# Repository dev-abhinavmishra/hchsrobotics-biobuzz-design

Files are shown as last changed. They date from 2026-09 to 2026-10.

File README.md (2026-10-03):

# BIOBUZZ-Robot

FTC BIOBUZZ-season robot CAD. Fully parametric FreeCAD model — Python
builders regenerate every `cad/*.FCStd` document from a shared
`Parameters` spreadsheet, and three selfcheck gate suites are the repo's
regression contract (all green on main). ~1,090 exportable solids across
six subsystem docs plus the integrated `master_robot.FCStd`, with full
fastener detail.

## For the CAD team (SolidWorks)

**You don't need FreeCAD.** Everything manufacturable is pre-exported to
STEP — the FCStd files are the editable sources only if you want to
change the design itself.

### What to open

| You want | Use |
|---|---|
| The whole robot, assembled | `exports/step/master_robot.step` (one AP203 STEP, ~1,090 parts, each at its true position) |
| One subsystem at a time | `exports/step/subassembly/{drivebase,intake,hopper,electronics,turret,lift}.step` |
| A group of related parts | `exports/step/subassembly/GRP_*.step` (frame, pods, turret rotation, fasteners…) |
| A single part | `exports/step/parts/<NAME>.step` — product names preserved (no anonymous Part__Feature) |
| 2D drawings | `exports/drawings/` — one A4 sheet per unique part as PDF + SVG (TOP/FRONT/RIGHT views, overall dimensions, title block with material + qty), and `exports/drawings/dxf/` R12 flat profiles for the 165 plate parts (ready for waterjet/laser) |
| Bill of materials | `exports/bom/bom.csv` — subsystem, description, material, spec, qty |
| Renders | `exports/renders/*.png` — shaded orthographic previews per subsystem |

### SolidWorks import notes

1. `File → Open → master_robot.step`, import as **assembly** (not
   multibody part). ~1,090 parts — give it a minute. For quicker work,
   import a subsystem STEP instead and mate them yourself (they're in
   world coordinates — parts land exactly where they sit in the master).
2. Units are mm. Part names carry a status suffix (`_VERIFIED`,
   `_VENDOR-PENDING`, `_UNVERIFIED`) — see the checklist below.
3. Non-physical construction geometry (`TOOL_`, `VOL_`, `ENV_`, `REF_`,
   `AXIS_` prefixes) is intentionally excluded from STEP — if you see it,
   it came from an FCStd, not an export.

### Before you cut metal: the verification checklist

Every dimension carries a status label in `exports/parameters.csv`
(and `docs/robot-parameters.md`): **3 VERIFIED** (manual-cited),
**24 VENDOR-PENDING** (goBILDA catalog values awaiting datasheet), and
**245 UNVERIFIED** (assumed). Nothing UNVERIFIED has been measured
against physical hardware — the gates verify parametric integrity,
mounting/declared-contact consistency, envelope fit, and rebuild
determinism, **not** real-world fit.

Measure/confirm before manufacturing, roughly in order of risk:

- **Stock + hardware dims**: all sheet/plate thicknesses, extrusion
  sizes, bearing bores — anything your parts physically mate to
- **Vendor parts**: all `VENDOR-PENDING` goBILDA dims vs the actual
  purchased parts (datasheet or calipers)
- **Ball-path clearances**: column bore Ø99 vs your ball's true
  diameter; chute width 97 mm; port window height
- **Mesh/engagement**: 72T ring + 14T pinion at 72.8 mm center distance;
  belt/chain center distances; lazy-susan race stack heights
- **Mounts**: every fastener lands in a real declared bore (the gates
  prove this geometrically) — but hole sizes/threads are UNVERIFIED
- **Envelopes**: stowed 453.7×454.5×379.0 mm inside the 457.2 cube;
  deployed lift tops 586.5 mm (inside the 609.6 reach / 736.5 height)

### Known design-contact notes (intentional touches/brushes)

- `PORT_FLANGE` sill: the ball rides over the port sill edge on the way
  out (designed ride surface, ~0.5 mm brush).
- `SCRW_CHL_1_0` (leg-2 lip tip) and `ROPE_DYNEEMA` (lift line): the
  ball brushes these ~2–5 mm on the cradle drop — acceptable grazing
  contact for hand-loaded parts; move the rope guide ~8 mm west if it
  ever deflects a ball in testing.
- `CHUTE_PTS + n·46.5` is the *ride* model only — the ball enters leg 1
  on a ballistic transition, rides the bed, and free-falls ~40 mm into
  the cradle mouth (see `dt_lift.py` comments).

### Change the design?

See "Quickstart" below — edit `scripts/freecad/robot_params.py` or the
`dt_*.py` builders, rebuild the affected doc, re-run the gates, then
re-export (`export_step.py`) and re-draw (`make_drawings.py`). The CI
workflow runs all of it on every push to `main`.

---

## Interactive 3D design review

`viewer/` is a self-contained Three.js design-review app for the full
competition robot concept — no CAD software needed:

```bat
cd viewer
python serve.py        :: no-cache dev server (avoids stale JS modules)
:: open http://127.0.0.1:8017
:: `python -m http.server 8017` also works, but hard-refresh if modules look stale
```

Features: 7 subsystems / ~270 placed parts merged into 136 BOM lines, per-part
inspector (spec, qty, notes, bounding size, connected-parts graph), an
**Isolate** button that ghosts everything but the selected part — combined with
Prev/Next it steps through every piece in solo view — exploded view slider,
X-ray and subsystem isolation, animated
mechanisms (mecanum rollers, flywheels, 360° turret, hood, agitator, 2-stage
deposit lift with live rope rigging), a launch demo that slews the turret,
lobs a POLLEN into the HIVE cell and tips it, a lift demo that raises the
cradle ~14.6" and tips the ball, an 18" sizing-cube overlay, and a full
BIOBUZZ field at scale (hives, 4 flowers, loading zones, staged elements).

**Part Explorer** (`Parts` tab in the left panel): every BOM line is listed
per subsystem with a live filter; clicking a part highlights all placed
instances and frames them. The inspector shows spec, quantity, bounding size,
notes, and a **Connected parts** graph — clickable chips jump between mated
parts (motor → pinion → axle → bearings → wheel; winch → spool → rope →
pulleys → stages; hubs → every wire run). Prev/Next steps through the whole
BOM, and **◎ Isolate** solos any part — the solo view follows selection so
stepping parts keeps everything else ghosted.

Production-realism pass: procedural canvas textures (alliance number plates,
AprilTags, foam-tile waffle, motor/hub labels), full wiring loom (motor power,
servo PWM, encoder/sensor JST, battery→switch→hub, slip-ring to the turret),
instanced fastener fields, sealed bearings, #25 chain with pins and a master
link, rail end caps, nylocks, shaft collars, compact-motor clamps, JST wire
connectors, hub LEDs, main-switch detail, zip ties, and a contact shadow.

Performance: repeated geometry (mecanum/omni rollers, star discs, wheel ribs,
slots, spokes, ports, fasteners) renders through InstancedMesh — roughly 200
meshes collapsed into instanced draws; clear polycarbonate uses cheap
alpha-blend instead of a transmission pass (which would double the scene
render), and the shadow map re-bakes only while geometry actually moves.

**Match Demo** (`⏵ Match Demo` button): a ~45-second scripted match —
autonomous pollen intake run (intake rollers spin, balls sweep along the
floor and arc up the throat), turret aims at the CELL AprilTag, feed wheel
meters balls **visibly rising through the clear column** into 3 POLLEN lobs,
teleop mecanum strafe to the alliance NECTAR stash, 2 NECTAR launches that
tip the HIVE, a corner run where the diverter kicks a ball down the load
chute into the cradle, then the lift rises and pours it into the FLOWER
mouth, and a loading-zone park. Cinematic chase/fixed cameras with phase
captions — **drag anytime to take a free spectator camera**, then "Resume
cinematic camera" to hand control back. Subsystem motion is gated per phase
(intake spins only while collecting, flywheels only while shooting). Every
scored ball stays in the cell. Click the button again to abort.

Design intent: 17.5×17.5×14.9" — starts legal inside the 18" cube (R101); the
deposit lift is the only expansion and tops out ~26", inside the R105 29"
vertical cap with hard-stop collars (G416). Over/under intake → inclined
hopper → feed column through the turret axis → dual-flywheel turret launcher
with AprilTag camera lobs POLLEN/NECTAR into the HIVE cell. For FLOWERS the
same column doubles as the elevator — a servo Y-flap diverts a ball through a
side port into the lift cradle, which deposits NECTAR into the ~4" mouth at
~22" (a lob into a 4" opening for a 3.6" ball was rejected as unreliable).

---

## Layout

```
cad\                  master_robot.FCStd (styled view baked in) +
                      master_robot_view.FCStd (styled copy)
cad\drivebase\        drivebase.FCStd     cad\intake\    intake.FCStd
cad\electronics\      electronics.FCStd   cad\hopper\    hopper.FCStd
cad\turret\           turret.FCStd        cad\lift\      lift.FCStd
cad\archive\          timestamped backups (auto-created before overwrites)
scripts\freecad\      build_*.py builders, selfcheck_overhaul*.py gates,
                      partkit/dt_* helpers, export/drawing/render tools
scripts\freecad\legacy\  superseded pre-overhaul concept scripts
scripts\validation\   ci_selfcheck.sh + probes
docs\                 project documentation (see index below)
exports\              STEP parts/subassemblies, bom.csv, mount_graph.json,
                      meta/, renders/, drawings/ (see exports/README.md)
viewer\               self-contained Three.js design-review app
.devin\               agent instructions and generator state
.github\workflows\    cad-verify.yml — rebuild + gates on every push to main
```

## Quickstart

Requires FreeCAD **1.1.3** (`freecadcmd` on PATH — AppImage extract or apt;
gate signatures are version-sensitive, other 1.1.x builds may differ):

```bash
freecadcmd scripts/freecad/build_drivebase.py
freecadcmd scripts/freecad/build_electronics.py
freecadcmd scripts/freecad/build_intake.py
freecadcmd scripts/freecad/build_hopper.py
freecadcmd scripts/freecad/build_turret.py
freecadcmd scripts/freecad/build_lift.py
freecadcmd scripts/freecad/build_master_robot.py   # integrated assembly
```

Exports + previews (regenerate after rebuilding):

```bash
freecadcmd scripts/freecad/export_step.py      # STEP parts/subassemblies + bom/meta
freecadcmd scripts/freecad/render_png.py       # exports/renders/*.png
freecadcmd scripts/freecad/make_view_copy.py   # restyle master_robot_view.FCStd
freecadcmd scripts/freecad/make_drawings.py    # exports/drawings/: A4 PDF+SVG
                                               # sheets + plate DXFs + manifest
```

Regression gates (must stay green — these are the repo's contract):

```bash
bash scripts/validation/ci_selfcheck.sh   # all selfcheck_overhaul* gates,
                                          # or run each directly:
freecadcmd scripts/freecad/selfcheck_overhaul01.py   # 45 gates
freecadcmd scripts/freecad/selfcheck_overhaul02.py   # 61 gates
freecadcmd scripts/freecad/selfcheck_overhaul03.py   # 73 gates
```

The `.github/workflows/cad-verify.yml` workflow runs the same build +
gates on every push to `main` (cached FreeCAD 1.1.3 install) and uploads
selfcheck output + `exports/` as artifacts.

Viewing in the FreeCAD GUI: just open `cad\master_robot.FCStd` (or the
identical `cad\master_robot_view.FCStd`). The file carries baked-in view
state: non-physical `ENV_*`/`VOL_*`/`REF_*` volumes and field markers are
hidden, subsystem solids are colored, and the camera opens on a fitted
isometric. Re-run `make_view_copy.py` after any rebuild to restore that
styling; `view_robot.py` does the same for a live session (Macro ->
Macros -> Run).

All scripts are idempotent and resolve paths relative to their own location.
See `docs/setup.md` for details and `docs/coordinate-system.md` for the axis
convention used by every model.

## Documentation index

- `docs/setup.md` — FreeCAD install path + exact build commands
- `docs/robot-parameters.md` — every named parameter: value, unit, status, source
- `docs/coordinate-system.md` — origin and axis convention
- `docs/cad-architecture.md` — how the FCStd files are structured and rebuilt
- `docs/mechanism-architecture.md` — placeholder plan for all six subsystems
- `docs/requirements.md` — manual-cited constraints vs assumptions
- `docs/design-decisions.md` — why things are built the way they are
- `docs/open-questions.md` — unresolved questions
- `docs/change-log.md` — build history
- `docs/eval-sprint03-independent.md` — independent adversarial eval of the
  gates + probes (ball-path findings, since fixed)
- `docs/initial-autonomous-build-report.md` — what the autonomous build produced

## Honesty notice

`VERIFIED` values are cited to a Competition Manual rule/section;
goBILDA-catalog values are `VENDOR-PENDING` pending datasheet/purchase;
everything else is an assumption labeled `UNVERIFIED`. The selfcheck gates
verify parametric integrity, mounting/declared-contact consistency,
envelope fit, and rebuild determinism — the UNVERIFIED checklist above is
what still needs a human + physical hardware.

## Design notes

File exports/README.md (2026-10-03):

# Exports — sprint-04 (as-built)

Generated by `scripts/freecad/export_step.py`,
`scripts/freecad/make_drawings.py`, `scripts/freecad/render_png.py`, and
the `selfcheck_overhaul0{1,2,3}.py` gate transcripts (rerun after any
rebuild). All artifacts derive from the parametric FreeCAD model —
FreeCAD is the source of truth; these files are read-only derivatives.

## Layout

| Path | Contents |
|---|---|
| `step/parts/<NAME>.step` | One AP203 STEP per exportable solid (1089 files). PRODUCT records carry the FreeCAD object names — reimported parts come back named, not anonymous Part__Feature blobs. Each is positioned by its object's global placement — import matches the FCStd exactly. |
| `step/subassembly/*.step` | Assembly-group STEP files (GRP_DRIVEBASE, GRP_FRAME, GRP_PODS, GRP_ELECTRONICS, GRP_INTAKE, GRP_HOPPER, GRP_TURRET, GRP_TURRET_ROT, GRP_LIFT, GRP_FASTENERS) plus subsystem slices (`drivebase.step`, `electronics.step`, `intake.step`, `hopper.step`, `turret.step`, `lift.step`). |
| `step/master_robot.step` | The complete master assembly in one STEP. Reimported and solid-counted as part of the export gate. |
| `drawings/` | Engineering-drawing output from `make_drawings.py`: one A4-landscape sheet per unique part (580 sheets) as PDF + SVG with TOP/FRONT/RIGHT views, overall-dimension callouts and a title block, plus flat R12 DXF profiles in `drawings/dxf/` for the 165 plate-like parts. See `drawings/README.md`. |
| `bom/bom.csv` | Bill of materials aggregated across subsystem BOM rows — subsystem, description, material, spec, status, qty, object list. |
| `parameters.csv` | Every `Parameters` spreadsheet alias: value, unit, status, source note. Mirrors `docs/robot-parameters.md`. |
| `mount_graph.json` | The declared pair tables: joints (members + bolts + nuts), faces, embeds, journals, contacts, ground census, BOM rows — what GEO/FAST gates verify. |
| `meta/<tag>.json` | Same pair tables per document (drivebase / electronics / intake / hopper / turret / lift / master). |
| `renders/*.png` | Shaded orthographic previews (`render_png.py`): front/side/top/iso per document, subsystem palette. |
| `selfcheck_overhaul0{1,2,3}.txt` | Latest gate transcripts (45, 61 and 73 gates respectively — all PASS). |

## Status labels

Every exportable solid name/label carries a status suffix:
`_VERIFIED` (manual-cited), `_VENDOR-PENDING` (goBILDA-catalog, awaiting
datasheet), `_UNVERIFIED` (assumed). Construction intermediates are
`TOOL_`-prefixed with unique status-bearing labels so no solid exports
an unlabeled or duplicated label (PROV1/PROV2 gates).

## Notes

- The ball route: intake mouth → inclined hopper floor → feed wheel →
  clear column bore → metering gate → turret launcher (POLLEN into the
  HIVE cell), or — with the Y-flap diverter — out the `COL_PORT`
  window → `PORT_FLANGE` → two-leg LOAD_CHUTE → lift cradle → FLOWER
  mouth (NECTAR).
- The yaw drive is an external ring mesh: 72T ring on the turret's
  outer rim driven by a 14T pinion at 72.8 mm centre distance, yaw
  servo mounted at −Y of the turret axis under the deck.
- The lazy-susan Z-stack is resolved bottom-up: deck 244–248 mm,
  susan races 248–256.5 mm, ring gear 256.5–263 mm, plate 263–267 mm.
- The load chute is two legs (28.5° and 21.8°) from the column port to
  the cradle's Ø99 mm park bore at z ≈ 140 mm.
- The electronics expansion hub sits on the right frame rail outer
  face (|y| ≈ 200 mm).
- Values marked UNVERIFIED/VENDOR-PENDING are placeholders pending
  measurement or datasheet confirmation — see
  `docs/robot-parameters.md` before manufacturing.
- The frame footprint is 444.5 mm square; enumerated fastener classes
  protrude up to ~3 mm into the start-cube margin.
- Older deliverables live under `../cad/archive/` (pre-overhaul FCStds)
  and `../scripts/freecad/legacy/` (concept scripts).

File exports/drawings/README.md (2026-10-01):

# exports/drawings/

Engineering-drawing output, generated by
`freecadcmd scripts/freecad/make_drawings.py` (see that file's docstring
for the environment-variable selectors).

- `<doc>_<part>.svg` / `<doc>_<part>.pdf` — one A4-landscape sheet per
  unique part (identical instances are grouped and shown as QTY): TOP,
  FRONT and RIGHT-SIDE views, overall extent-dimension callouts on each
  view, and a title block (part, material, spec, qty, rev, scale).
- `dxf/<doc>_<part>.dxf` — flat R12 profile for every plate-like part
  (thin+wide geometry, or a plate-hint name such as deck/base/cheek/
  bracket/pan/gusset), face-normal rotated to +Z, origin at the
  bounding-box minimum. Ready for laser/waterjet nesting.
- `manifest.json` — machine-readable per-part report (doc, qty, bbox,
  material, plate flag, output paths).
- `manifest.txt` — the same per-part list as printed on stdout.
- `sample/` — a few representative sheets + DXFs kept in-repo for
  review. The full per-run output (~1,150 sheet files + ~190 DXFs,
  ~140 MB) is gitignored; regenerate it any time with the command
  above.

Regenerate after any geometry change; the part list is enumerated from
the documents, not hardcoded.

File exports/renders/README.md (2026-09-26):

# exports/renders — BIOBUZZ-Robot

Rendered previews of the placeholder master assembly:

- `master_{front,side,top,iso}.svg` — shaded vector renders
  (`render_views.py`): painted facets, per-subsystem colors,
  silhouette/sharp-edge overlay, legend.
- `master_{front,side,top,iso}.png` — shaded raster renders
  (`render_png.py`): z-buffered so interpenetrating solids occlude
  correctly; same palette and views as the SVGs.
- `fc_screenshot.png` — reference capture of the styled GUI view
  (`cad/master_robot_view.FCStd`, produced by `make_view_copy.py`).
- `render_log.txt`, `view_log.txt` — script run logs.

Every file in this folder is prototype material:
**PROTOTYPE / VERIFY BEFORE MANUFACTURING**

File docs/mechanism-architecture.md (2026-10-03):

# Mechanism architecture — BIOBUZZ sprint-01 foundation

Sprint 01 rebuilt the foundation (frame + drivetrain + odometry pods +
electronics tray) in `cad/master_robot.FCStd`, with
`cad/drivebase/drivebase.FCStd` and `cad/electronics/electronics.FCStd`
as subsystem slices. All three documents are generated by thin wrappers
over the shared builder `scripts/freecad/dt_build.py`, so subsystem
geometry is byte-for-byte identical to the corresponding master regions
(DET3 gate verifies name + bbox + volume parity).

Every number below is cited (VERIFIED), goBILDA-catalog-representative
(VENDOR-PENDING), or assumed (UNVERIFIED) on the same line; canonical
values live in `docs/robot-parameters.md` and the `Parameters`
spreadsheet inside each FCStd. Frame convention:
`docs/coordinate-system.md` (+X forward, +Y left, +Z up, origin on the
tile at the footprint center).

## Frame — goBILDA 1120-series U-channel ring

- `FRAME_RAIL_L/R`: two 444.5 mm U-channels (`rail_size` 48 mm
  VENDOR-PENDING, `rail_wall` 2.5 mm UNVERIFIED), lateral offset
  `rail_lat_off` = `wheel_lat_off − wheel_out_gap` so the rail inner
  face clears the wheel envelope. Real wall-grid hole rows cut through
  flange and web faces; axle-clearance bores let the drive shafts pass.
- `FRAME_CROSS_B/F`: front/rear crossmembers at `cross_x_off`, ends
  bolted into the side-rail inner faces (`tie_web` joints).
- `GUSSET_UR/UL/BR/BL` inside-corner brackets + `GUSSETU_/GUSSETX_`
  twin plate rows, 4 fasteners per gusset (rail + crossmember split).
- `CROWN_POST_L/R` stand the crown structure off the rail tops;
  `ENDCAP_*` close the six open channel ends.
- `BELLY_PAN` 2 mm sheet (`pan_z` 26.67) hung under the frame by six
  `PAN_BRKT_*` L-brackets (2 leg bolts + 1 foot bolt each) plus four
  front/rear pan bolts — the pan carries the battery, switch bracket,
  and the odometry spring pads.
- `PLATE_NUM_*` number plates (front + side), `TIE_RB_*` rear-brace
  ties.
- `DECK_*`: 3 mm deck panels at `deck_z` 85.3 held by eight
  `DECK_POST_*` standoffs off the rail webs (post_foot + deckpost_web +
  deckpost_panel joints).

## Drivetrain — 4× 96 mm mecanum (corner-parameterized)

Each corner (`build_corner`, tags FL/FR/RL/RR) is generated by the same
code path with only sign flips — there is no per-corner copy-paste:

- `WHEEL_ASSY_*` `App::Part` carrier at `wheel_lon_off`/`wheel_lat_off`/
  `wheel_dia/2`; children hold local-frame geometry:
  - `WHEEL_HUB_*`: Ø26 hub (`hub_dia`) with a real hex REX bore
    (`rex_af` 8 mm VENDOR-PENDING) and a radial `BOLT_HUB_*` M4 pinch
    setscrew into the shaft flat.
  - `WHEEL_PLATE_*_IN/OUT`: Ø92 side plates (`wplate_dia`), chamfered,
    sharing the hub's hex bore; rollers trapped between them.
  - `ROLLER_*_00..09_B`: ten Ø14×24 rollers (`mec_roll_*`) on 45° slant
    axes — the tire-contact census registers all ten per wheel.
- `AXLE_*`: hex live axle through the hub's hex bore, M8-threaded tip
  (`shaft_tip_d`/`shaft_tip_len`) carrying `WSH_`/`NUT_AXLE_`/
  `COLLAR_` retention and a `PINION_` drive dog.
- `BRG_IN_*`/`BRG_OUT_*`: flange bearing blocks (`bear_*` dims) flush
  on the rail cavity faces, **real Ø9.6 REX clearance bores centered on
  the wheel axis** (the bore + pilot sit at the block center — an
  earlier revision bored them at the plate corner, which would have
  trapped the axle in solid metal). 4 flange bolts each → cavity
  rivnuts.
- `MOTOR_*`: 5203-class Ø36 can + Ø40 gearbox (`motor_*`,
  VENDOR-PENDING), hex socket bore for the axle tail, 4 face taps.
  Motor face registers on `MOUNT_PLATE_*` (348.5×48.3×3.05 mm,
  `mplate_*`) which bolts to the rail inner face with 12 countersunk
  `BOLT_MPL_*` + cavity nuts. `CLAMP_*_1/2` split-ring clamps cradle the
  gearbox can (declared curved-face contact, not a journal) with shared
  ear bolts through clamps + plate + wall.
- `PINION_*` on the outboard shaft end + axle `WSH_`/`NUT_AXLE_` lock
  stack.

## Odometry pods — 3 tracking wheels

- `ODO_MOUNT_*` blocks bolted under the belly pan (`odo_mount` joint);
  `ODO_PIVOT_*` pins carry `ODO_ARM_*` swing arms with real journal
  pairs (`odo_pivot`).
- `ODO_WHEEL_*` Ø48 tracking wheels (`odo_wheel_d` VENDOR-PENDING) on
  `ODO_AXLE_*` pinions through arm bores (`odo_wheelpin` journal) —
  exactly three ground contacts besides the four mecanums (ground
  census gate).
- `ODO_SPRING_*`: wire-formed preload struts (polyline + ball) from the
  arm tail to a pan pad — declared spring contacts, geometry baked
  (not param-bound) by contract.
- `ODO_ENC_*` encoder body per pod with `SCRW_ENC_*` self-taps.

## Electronics — belly-tray package

- `ELEC_SHELF` 2 mm tray at `shelf_z` 85.3 on four `STANDOFF_*`
  (shelf_so joints). `HUB_CTRL` mounts to the belly pan; `HUB_EXP`
  is face-mounted on the `FRAME_RAIL_R` out-wall via a fused 3 mm
  back flange + 4 M4 bolts to cavity nuts (the shelf site sits
  inside the S17 seat sphere envelope).
- `BATTERY` 95×65×40 (`batt_*`) on the belly pan, strapped by
  `BATT_STRAP_0/1` (strap_pan joints + pan-side nuts).
- `SWITCH_BRKT` on the pan face (2 pan bolts) with `MAIN_SWITCH` and 2
  `SCRW_SW_*` self-taps.
- Sprint-01 wiring subset: `WIRE_BATT_SW`, `WIRE_SW_CTRL`,
  `WIRE_HUB_RS485`, four `WIRE_MTR_*` motor leads, three `WIRE_ENC_*`
  encoder leads — both endpoints must exist; harness segments are
  baked (`wire_d` Ø3) and declared via contact/embed pairs.

## Fastener model (R7 hybrid)

- Every bolt is a real solid (`pk.bolt`/`_flathead`/`pk.hex_nut`/
  `pk.rivnut`) spanning its joint: **real clearance bores through
  pass-through members**, embed declared only into the terminal
  threaded member (`meta['embeds']`).
- `meta['joints']` records per-joint membership + bolt/nut lists;
  FAST1 enforces per-class minimums (bearing 4/motor-face 4/mount
  plate 12/clamp 2/gusset 2+2/post 4/pan-bracket 2+1/odo 2+1+1/…).

## Declared-pair tables

`dt_build.finish_doc` writes `exports/meta/<tag>.json`:
`joints` (member/bolt/nut sets), `faces` (mount face pairs, GEO3
≤0.1 mm), `journals` (coaxial shaft↔bore pairs, GEO4 ≤0.2 mm),
`embeds` (terminal fastener + press-fit embeds), `contacts`
(spring/wire/incidental touch), `ground` (exactly 4 mecanum + 3
odometry wheels), `bom` (per-subsystem spec rows → `exports/bom/bom.csv`).

## Verification

`selfcheck_overhaul01.py` gates 21 checks: GIT (sources committed),
DET (shared-builder parity), PAR (alias set + bound expressions),
PROV (status labels), DAG (pair references), ASM (group coverage),
FAST (joint hardware), GEO (census, undeclared overlap ≤0.5 mm³,
mount contacts ≤0.1 mm, journal axes ≤0.2 mm, motor axes ≤0.3 mm/1°),
ENV (envelope bounds), XPT (per-part/subassembly/master STEP, tables),
GUI (doc health). Current: **21/21 PASS**.

## Sprint-02/03 scope guard

Intake, hopper, turret/shooter, lift, servos, camera, and USB-loom
solids are intentionally absent from the master — they belong to
later sprints. Do not add them.

# Sprint-02 — game-piece path (intake + hopper/feed)

Sprint 02 builds the under-crown ball route on the same frame, shared
through `dt_path.py` into `cad/intake/intake.FCStd`,
`cad/hopper/hopper.FCStd`, and `cad/master_robot.FCStd` (DET3 parity).
Frame convention unchanged (+X forward, +Y left, +Z up; the hopper
occupies the -X half).

## Intake — over/under dual roller

- `INT_CHEEK_L/R`: cheek plates flush-bolted to the rail inner walls
  (`cheek_lat_off` 130.5), pivot pins + crown-post lock bolts
  (`cheek_pivot`/`cheek_lock` joints) — the whole assembly swings
  between stowed and deployed poses.
- `ROLLER_LOW`: full-width Ø50.8 ribbed traction roller
  (`roller_low_r` 25.4) on a wall-borne hex axle, driven from the
  intake motor through a #25 chain run inside the right rail channel
  (`SPROCKET_9T`→`SPROCKET_16T`, `MASTER_LINK` clip joint).
- `ROLLER_TOP`: Ø78.7 compliant star roller (`roller_top_r` 39.35 on a
  `star_core_r` 22 core) on `FLOAT_SLIDE_*` acetal blocks —
  `float_travel` 17.8 mm of sprung travel absorbs Ø91 NECTAR.
  `SPRING_POST_*` Ø8 posts stand on the cheek towers; the
  `TORSION_SPRING_*` coils wind snug on the exposed post span outboard
  of the cheek face, leg tips seating into the slide + cheek faces
  (declared embeds).
- `BELT_XROLL` crossed quarter-twist belt counter-rotates the star
  roller off the lower axle — the crossing survives the 17.8 mm float
  where a rigid spur pair could not. `TENS_ARM` + `TENS_IDLER` ride on
  the `TENS_POST` pivot; `TENS_SPRING` preloads the arm (coil on the
  post's exposed span, legs into arm + cheek faces).
- `THROAT_GUARD`: crown-top deflector into channel nuts.
- Nip geometry: `nip_rest_gap` ≈ 81.6 ≥ 73.2 for POLLEN at rest, opens
  ≥ 91 for NECTAR at full float.

## Hopper — inclined magazine + clear feed column

- `HOP_FLOOR`: inclined magazine plate (`hopper_incline` 20°) on
  wall-side ledges (`hop_ledge_*` joints), descending toward the feed
  corner. `HOP_APRON` lips under the floor's low edge (declared lap
  embed). `HOP_CURB` rear curb behind the column mouth.
- `HOP_WALL_L/R`: 3 mm walls at `hop_wall_y` ±60 bounding the lane.
  The L wall carries an `R76` notch clearing the +Y port corridor (the
  Ø93 sphere passes the wall, not just the flange bore).
- `AGIT_*`: agitator servo at the low corner (`agit_x/y/z`) + paddle
  + horn; bracket and servo each take 4 screws.
- `FEED_*`: compliant metering feed wheel (`feed_wheel_r` 40.65) on
  `FEED_SHAFT` through a wall bearing (`feed_bearing` joint, 4 bolts),
  1:1 spur drop pair from `FEED_MOTOR` under the incline
  (`SPUR_FEED_M/W` mesh declared as tooth-envelope embed).
  `FEED_SCOOP` guide plate at the column mouth.
- `FEED_COLUMN`: clear Ø110/Ø104 tube on the future turret axis
  (`column_x` −66), z 88→254, seated on `COL_FLANGE` (trimmed to the
  column's +X face) bolted through 4 `COL_POST_*` hex standoffs to the
  belly pan — each post carries a top flange bolt **and** a bottom
  pan bolt (col_post joints, 2 fasteners each).
  - `COL_WIN` +X feed window, ≈93+ clear aperture into the hopper
    lane — the Ø93 ball enters at window level.
  - `COL_GSLOT` slot in the -Y shell + `COL_GBR` horn bore admit the
    gate flag's swing.
  - `COL_PORT` +Y window (the diverter port) over `REF_DIV_PORT`.
- `GATE_*`: metering gate on the **-Y wall** — servo + 4-bolt bracket
  + horn through the wall bore — moved off the +Y corridor so the
  port sphere stays clear. `GATE_FLAG` blades through `COL_GSLOT`
  into the bore; open/closed sweep poses are real `VOL_GATE_*`
  probe solids.
- `DIV_*`: `DIV_BAND` clamp ring on the column (shrink-fit embed,
  +X arc notched at the window mouth) carrying `DIV_BRKT` + micro
  `DIV_SERVO` (4 screws) driving `DIV_SHAFT`/`DIV_FLAP`. The flap
  parks flat on the +Y bore wall **below** the port (VOL_DIV_A) and
  swings up to seal the straight-through route (VOL_DIV_B);
  `PORT_FLANGE` bolted collar (bore `div_port_d` 100, ≥93+margin)
  centered at z 204 on the +Y wall.
- `SNSR_*`: entry color sensor bracket + lens on the R wall.
- `VOL_BALL_P/N`, `REF_*`, `AXIS_*`: staged probe + interface datums
  (export-excluded).

## Ball path (as built, selfcheck-verified)

Ø93 NECTAR spheres at the declared A6 stations clear every static
solid (`common().Volume` ≤ 0.5 mm³): intake mouth (205,0,80) →
under-crown (178,0,85) → basin (105,0,155) → incline (62,0,142) →
lane (40,0,134) → approach (35,0,132) → window throat (10,0,125 —
re-sited per sprint-03 pin C4; (10,0,128) grazed the scoop) →
bore rest (…,162, resting on the curb top) → mid (200) → top (240) →
gate (−66,0,175) → port (−66,52,203) → flange (−66,57,204).
Swept poses (`VOL_GATE_OPEN/CLOSED`, `VOL_DIV_A/B`) clear statics the
same way. Moving members are exempt at their rest envelopes per the
contract's C1 clause.

# Sprint-03 — turret, launcher, flower lift

## Turret — lazy-susan yaw over the feed column

Static stack on the sprint-01 deck panels: `TOWER_L/R` 3 mm polycarb
risers (y ±130.8, z 86.8→244) with `TOWER_GUS_*` braces →
`TURRET_DECK` (4 mm, z244–248, Ø114 bore on the turret axis
x −66 y 0) → `LAZY_SUSAN_LO`/`HI` split races (z248–256.5 split at
z252.25, declared race-pair contact is the real load path) → `RING_GEAR` (72T, PD
121.9, external teeth, z256.5–263) → `TURRET_PLATE` (Ø170 × 4,
z263–267, Ø114 bore + scallops) carrying the rotating launcher stack
(`GRP_TURRET_ROT`).

Yaw drive: `YAW_SERVO` under the deck at (−66,−72.8) on `YAW_TRAY`,
`YAW_SHAFT` through the deck bore to `YAW_PINION` (14T, PD 23.7) —
external mesh at the pinned 72.8 mm center distance (internal mesh
rejected: the feed column occupies the inner radius). The pinion's
outer tip sweeps r58.9–86.7 about the turret axis, clearing the
column's Ø110 circle entirely. `HALL_SNSR` on the deck rim +
`YAW_MAGNET` in the plate rim index the rotation — both solids sit
at r78.74 from the axis.

## Launcher — dual counter-rotating Ø88.9 flywheels

`LAUNCH_CHEEK_L/R` at y ±66.5 (rotating-stack top z~379) carry
`FLYWHEEL_L/R` (Ø88.9 compliant,
face gap 73.7 → ~19% NECTAR compression) on `FLY_SHAFT_*` +
`FLY_BRG_*` bearings, driven by `FLY_MOTOR_L/R` 5203-class cans
(journal chain: motor stub → shaft → cheek bearing → hub clamp).
Axis at (−80, ·, 308.5) — raised from the viewer's 292 so the wheel
bottom (264.05) clears the column top and susan/ring stack.

`HOOD` (2 mm alu) pivots on `HOOD_PIV_L/R` Ø8 bearings through both
cheeks at z 359 (the viewer's 321 sat inside the wheel disc; 359
clears the raised wheel top 352.95). `HOOD_SERVO` + `HOOD_LINK`
pushrod articulate the exit angle; `VOL_HOOD_LO/HI` swept-pose probes
are selfchecked. `NIP_BACKPLATE` rotates with the turret and feeds
the column-top ball into the nip. `TURRET_TOP_BRACE` ties the cheek
tops; `VSN_CAM` + `CAM_LED` ride the plate rim; turret wiring is
baked service loops in the annular gap r55–80 below the plate.
`VOL_YAW_0..3` swept-yaw probes (r105 rim markers at 4 angles) clear
all statics.

## Flower lift — two-stage cascade mast on the left rail

`LIFT_BASE` (3 mm, z 63.75 rail top) carries `LIFT_RAIL_L/R`
(14 mm slides, ~269 tall, y 144/180) tied by `LIFT_TOP_TIE` (~334)
with `STOP_COLLAR_L/R` hard stops at z ~326 (R105/G416). Stage-1
`LIFT_S1_BAR_L/R` + `S1_TRUCK_*` blocks + `S1_TIE`; stage-2
`LIFT_S2_BAR` + trucks + `S2_TIE`. `LIFT_WINCH` + `WINCH_SPOOL`
drive the rigging; `ROPE_DYNEEMA` bakes the winch → top pulley →
stage-1 dead-end → traveling `LIFT_PULLEY` (2× rate) → stage-2 tie
run. `CRADLE_ARM` cantilevers `CRADLE_CUP` (Ø110 shell, Ø99 bore,
`CRADLE_FOAM` liner) on `CRADLE_PIV`; `TILT_SERVO` tips ~65° at full
extension. Deployed probes `VOL_S1_DEP`/`VOL_S2_DEP`/`VOL_CRADLE_DEP`
sit inside the R105 envelope (609.6 × 736.5; as-built deployed
top 586.5).

## Load chute — diverter port → cradle bowl

`LOAD_CHUTE` is a 97 mm-wide two-leg tray centered on the pinned path
(−66,56,204) → (−100,150,140) → (−118,178,120) — leg-1 32.6°, leg-2
31.0° (both ≥ 20°). `CHUTE_LIP_*` side lips flank each leg. The
socket tip sits inside the Ø100 port bore; `CHUTE_PORT_EAR` welds to
the port-flange face beside the bore (2 bolts into the ring annulus)
and the tray passes the `TOWER_L` slot on a `CHUTE_TOWER_PAD` strap
(2 bolts + nuts through the riser). The leg-2 west lip is notched
where it crosses the riser sheet.

## Ball path — launch + return (S13–S17, all Ø93)

S13 column-top exit (−66,0,254) → S14 nip throat (−80,0,308.5; nip
faces exempt per C1) → S15 chute leg-1 and S16 chute leg-2 — ball
centers derived from the built bed normals (+46.5·n̂ per pin C5) →
S17 cradle bowl. The chute carries no fasteners or lips across the
ball channel; swept-probe gates cover hood poses and deployed
stages.

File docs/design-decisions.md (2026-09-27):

# Design decisions — BIOBUZZ-Robot

## D1 — Parametric primitives, not baked shapes

Each solid is a `Part::Box` / `Part::Cylinder` whose dimensions are bound to
the `Parameters` spreadsheet via `setExpression` (e.g. `Length =
Parameters.chassis_width`). A `Part::Feature` with a baked `Part.makeBox`
shape has no bindable dimensions, so a parameter change could not propagate.

Rationale: a reviewer can change `chassis_width` in one cell and watch every
bound dimension update — the foundation stays editable instead of becoming
frozen geometry.

## D2 — Paths resolved from `__file__`, never from cwd

Both build scripts compute the project root as
`Path(__file__).resolve().parents[2]`. No absolute paths, no reliance on the
current working directory.

Rationale: the same script runs identically from the repo checkout, from a
copied mirror tree, or under an unrelated working directory — which is also
how the evaluator verifies portability.

## D3 — Placeholder volumes only, every assumption labeled UNVERIFIED

The models contain packaging volumes (envelopes, chassis box, wheels, motors,
battery, electronics) — no gears, no mechanisms, no invented detail. Anything
not cited to the Competition Manual carries `DataStatus = "UNVERIFIED"`.

Rationale: an honest placeholder that a team can measure against beats a
detailed-looking model that smuggles in invented numbers. Verified values
(R102, R105, §9.x) are labeled `VERIFIED` with their citation.

## D4 — Always rebuild fresh; archive only foreign content

On each run the scripts rebuild the document from scratch, which makes the
object set identical every time. If the target FCStd contains objects the
script did not create, a timestamped copy is written to `cad\archive\` first.

Rationale: idempotent rebuilds keep the CAD reproducible, while the archive
policy protects any hand-edited content from silent loss.

## D5 — Millimetres everywhere, origin at footprint center on the tile

All models use mm and share one convention: origin at the center of the robot
footprint on the tile surface, +X forward, +Y left, +Z up, Z=0 at tile top
(`docs/coordinate-system.md`).

Rationale: mm is FreeCAD's native unit and matches the manual's metric
equivalents; a centered origin makes mirrored quadrant placements (wheels,
motors) trivially symmetric.

## D6 — Project root is the OneDrive Documents folder (settled 2026-09-20)

The project lives at `C:\Users\pmsma\OneDrive\Documents\BIOBUZZ-Robot`. The
original mission text referenced `C:\Users\pmsma\Documents\BIOBUZZ-Robot`,
which does not exist on this machine. User confirmed 2026-09-20: keep the
OneDrive location.

Rationale: user decision; all build scripts resolve the root relative to
`__file__` anyway, so scripts are unaffected by where the tree sits.

## D7 — goBILDA build ecosystem (team direction, pending purchase)

Team plans to buy into the goBILDA ecosystem (settled 2026-09-20). Wheels,
motors, channels, and structure placeholders should use goBILDA-catalog-
representative sizes.

Status: direction is decided; hardware is NOT yet purchased, so all
goBILDA-derived dimensions remain UNVERIFIED until measured against real
parts or cited from goBILDA datasheets (e.g. 96 mm mecanum wheels are a
goBILDA staple — still verify exact width/bore before manufacturing).

## D8 — Two-phase scoring architecture (team direction, settled 2026-09-20)

Scoring splits into two mechanisms rather than one shared scorer:

- Early game (Auto + most of TeleOp): a shooter that prioritizes launching
  Pollen (~71 mm dia, VERIFIED §9.8) into the Hive cell.
- Final 60 s of TeleOp: a top-mounted lifter that places Nectar (~91 mm
  dia, VERIFIED §9.8) into Flower tops — opening ~101.5 mm dia at ~546 mm
  height (VERIFIED §9.7) — where Nectar cannot be removed and decides
  flower ownership by top-most placement.

Rationale: maximizes endgame flower points while keeping the hive-tipping
game loop simple. The implications flagged at D8 time — shooter Nectar
capability and lifter mechanism type — were settled 2026-09-20 by D10
(universal ~100 mm bore, Nectar-capable) and D11 (cascade elevator);
the remaining diverter/hopper feed path is a tracked question in
`docs/open-questions.md`.

## D9 — Drivetrain: 4× 96 mm goBILDA mecanum (settled 2026-09-20)

Four goBILDA 96 mm mecanum wheels in mirrored quadrants, one motor each.

Rationale: holonomic strafing aligns the shooter to the Hive cell and the
lifter to the narrow ~101.5 mm Flower top opening without turning the
chassis. Hardware not yet purchased — dims stay VENDOR-PENDING.

## D10 — Shooter: dual flywheel, universal ~100 mm bore (settled 2026-09-20)

Counter-rotating flywheel pair launches Pollen (~71 mm, VERIFIED §9.8) and
must also accept Nectar (~91 mm, VERIFIED §9.8) — bore ~100 mm assumed,
UNVERIFIED pending prototyping.

Rationale: dual-flywheel is the standard FTC ball launcher (compact,
controllable, channel-fed); a universal bore enables mixed-load Hive tips
and a backup flower-dump path at small packaging cost.

## D11 — Lifter: cascade elevator (settled 2026-09-20)

Top-mounted goBILDA cascade/linear-slide elevator carries a Nectar cradle;
stows inside the 457.2 mm start cube (VERIFIED R102), deploys within the
457.2 × 609.6 × 736.5 mm expansion volume (VERIFIED R105) toward the ~546 mm
Flower top (VERIFIED §9.7).

Rationale: a pure-vertical lift keeps the cradle centered over the narrow
~101.5 mm Flower opening; an arm's arc would make the precise top-load
harder.

## D12 — Datasheet-driven width corrections (settled 2026-09-20, sprint-06)

`wheel_width` corrected 25 → 32 mm and `motor_dia` 40 → 36 mm after the
goBILDA sources were fetched: 96 mm mecanum wheel set 3213-3606-0002 and
its dimension schematic 3606-0000-0096 (Ø96 × 32 mm, Ø14 rollers, ~10 per
wheel at 45° slant, 207 g), plus the Yellow Jacket 5203-series motor page
(Ø36 gearbox, 8 mm REX shaft). `intake_width` narrowed 330 → 326 mm as a
consequence: at the cited 32 mm wheel width, wheel inner faces sit at
±164 mm and the intake frame must clear them (~1.4 mm margin retained).
Roller placeholders are modeled as straight cylinders tangent to the Ø96
datasheet envelope (`mec_roll_len` = 20 keeps flat end caps inside it).

Rationale: values now trace to a real vendor document instead of invented
placeholders; statuses stay VENDOR-PENDING (not VERIFIED) until physical
measurement. The ~1 mm intake-to-wheel clearance is a placeholder-fidelity
limit, flagged as UNVERIFIED — the real intake design must revisit this
gap.

## D13 - Viewer deviations corrected during CAD overhaul (sprint-02, UNVERIFIED pending team review)

Two viewer-robot.js fudge geometries turned out to be physically
impossible once the sprint-02 intake was dimensioned honestly; both were
corrected in CAD (approved by the planner + evaluator as honest-physics
corrections):

1. Compliant star roller repositioned (X=133, Z=175, viewer had it at
   Z~91). At viewer coords the nip surface gap was -10.15 mm (rollers
   interleaved) and g + 17.8 mm float travel could never reach the
   91 mm NECTAR requirement. Separately, the under-crown throat is only
   ~71.8 mm, so the ball path physically must go OVER the crown into the
   hopper basin; the exit ramp became a THROAT_GUARD deflector.
2. Counter-rotation via crossed quarter-twist belt + sprung tensioner
   instead of the viewer's 1:1 24T spur pair -- a rigid gear mesh cannot
   hold across a 17.8 mm floating shaft (same 'defies physics' class as
   the original CAD rejection).

Sprint-04 obligation (planner condition): the viewer-consistency pass
flows these corrections BACK into viewer/js/robot.js so the viewer and
CAD reconverge -- the artifacts diverge only until sprint-04.

Sprint-03 interface contract (frozen): AXIS_TURRET, REF_DECK_IFACE
(bolt-circle + bore datum) and REF_DIV_PORT are published as
non-exportable REF_/AXIS_ datums in the sprint-02 Appendix tables --
sprint-03 builds against their letter.

Rationale: physical credibility (non-negotiable rubric criterion)
outranks viewer-matching; the corrections are documented rather than
silent.

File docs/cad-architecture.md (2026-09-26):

# CAD architecture — BIOBUZZ-Robot

## Files

- `cad\master_robot.FCStd` — top-level packaging model built by
  `scripts\freecad\build_master_robot.py`.
- `cad\drivebase\drivebase_concept_v01.FCStd` — drivebase concept built by
  `scripts\freecad\build_drivebase_concept.py`.
- `scripts\freecad\partkit.py` — shared component kit used by the two
  rebuilt files (rehaul sprint-01): predicate-based edge selection
  (`pred_axis`, `pred_radius`, `pred_at_z`), filleted plates, U-channel
  extrusions with hole grids + shaft notches, shafts, bored hubs,
  bearing blocks, bored motor face plates, fused roller+pin bodies, and
  `mecanum_wheel` which returns an `App::Part` carrier placed as a unit.
- `cad\master_robot_view.FCStd` and
  `cad\drivebase\drivebase_concept_v01_view.FCStd` — GUI-styled copies
  produced by `scripts\freecad\make_view_copy.py` (also injects
  `GuiDocument.xml` view state into the build targets in place).
- `cad\intake\intake_concept_v01.FCStd` — floor-intake concept built by
  `scripts\freecad\build_intake_concept.py`.
- `cad\transfer\transfer_concept_v01.FCStd` — transfer-channel concept built
  by `scripts\freecad\build_transfer_concept.py`.
- `cad\scoring\shooter_concept_v01.FCStd` — Pollen shooter concept built by
  `scripts\freecad\build_shooter_concept.py`.
- `cad\endgame\lifter_concept_v01.FCStd` — Nectar lifter concept built by
  `scripts\freecad\build_lifter_concept.py`.
- `cad\electronics\electronics_concept_v01.FCStd` — battery + control /
  expansion hub layout placeholders built by
  `scripts\freecad\build_electronics_concept.py`.
- `cad\archive\` — timestamped `.FCStd` copies written automatically before a
  script would overwrite a file containing objects it did not create (holds
  the sprint-01 `master_robot` snapshot taken before the sprint-02
  extension, plus staged `*_sprint02_*` backups of each concept taken before
  the sprint-03 mechanism-level upgrade).
- `cad\library` — reserved for future shared subsystem models.

## Document structure (all files)

- A `Spreadsheet::Sheet` named `Parameters` holds every named dimension:
  column A = alias, B = value (aliased cell), C = unit, D = status
  (`VERIFIED`/`UNVERIFIED`/`VENDOR-PENDING`), E = source.
- An `App::Part` container (`RobotAssembly` / `DrivebaseAssembly` /
  `IntakeAssembly` / `TransferAssembly` / `ShooterAssembly` /
  `LifterAssembly` / `ElectronicsAssembly`) groups all placeholder solids so
  nothing sits loose at
  the document root; FreeCAD's auto-created `App::Origin` children stay
  inside the container.
- In the master model a second `App::Part` (`COORD_REF_world_origin_axes`)
  groups the three axis-indicator solids.
- The master additionally carries `VOL_*` mechanism packaging reserves
  plus `MECH_*` representative solids inside them and `REF_*` field
  aiming markers (sprint-04)
  (intake, transfer, shooter, lifter stowed + deployed ghost) sharing alias
  names with the matching concept files.
- Construction intermediates (cut tools, pre-feature blocks, hole/pin
  solids) are named `TOOL_*` and grouped under a `Tools` App::Part. They
  are excluded from exports, renders, provenance sweeps, and the physical
  overlap scan; each must be consumed by a feature (Base/Tool link) so no
  tool floats unreferenced.
- Every placeholder solid is a parametric `Part::Box` / `Part::Cylinder`
  or a feature result (`Part::Cut` channels/cheeks, `Part::Fillet` pans/
  decks, `Part::Chamfer` face plates, `Part::Fuse` roller+pin bodies)
  whose `Length`/`Width`/`Height`/`Radius`/`Placement.Base.*` components
  are bound to `Parameters.<alias>` expressions (features inherit the
  bound upstream tools), so the model recomputes from the spreadsheet.
- Children of `App::Part` carriers (`WHEEL_ASSY_*` wheel sub-assemblies)
  keep local-frame shapes: `o.Shape` does NOT include the carrier's
  placement. Any geometric analysis (overlap/connectivity/export) must
  use `s = o.Shape.copy(); s.Placement = o.getGlobalPlacement()`.
- Every placeholder solid carries a `DataStatus` string property
  (`UNVERIFIED`, or `VERIFIED - <rule>` when all its dimensions are
  manual-cited) and a descriptive label — no bare `Box`/`Cylinder` names.

## Rebuild and archive policy

The scripts delete nothing by merging — they always rebuild a fresh document,
which keeps runs idempotent (same object names/labels every time). Before
overwriting, `archive_if_foreign()` opens the target: if any object is not in
the script's managed set (App::Origin children count as managed), a
timestamped copy goes to `cad\archive\` first. FreeCAD `.FCBak` sidecars are
removed after each save so `cad\` stays clean.

## Verification gate

`scripts\freecad\selfcheck_rehaul01.py` is the active contract gate
(rehaul sprint-01): PAR3 expression sweep, PROV1 provenance, ASM1
connectivity + mount chains, GEO1 open-channel ratio, GEO6 roller
slant/X-pattern, envelope discipline, C6 overlap scan against the frozen
declaration table, PAR5 parameter sweeps, fillet-survival probe, and GUI
view-state presence — run against BOTH the master and the drivebase
concept. `selfcheck_sprint06.py` is superseded but retained runnable
against the archived sprint-07 baseline (pass the archive path as
argv[1]).

## Coordinate convention

All models share the convention in `docs/coordinate-system.md`: origin at the
center of the robot footprint on the tile surface, +X forward, +Y left, +Z up,
Z=0 at the tile top. Parameter values and statuses are mirrored in
`docs/robot-parameters.md`.

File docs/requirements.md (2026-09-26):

# Requirements — BIOBUZZ-Robot

This file separates **manual-cited constraints** (VERIFIED against the BIOBUZZ
Competition Manual TU01) from **assumptions** (UNVERIFIED placeholders awaiting
measurement or team decision).

## Verified constraints (Competition Manual TU01)

| Constraint | Value | Source |
|---|---|---|
| Starting size limit | 457.2 mm cube (18 in side), self-contained | R101 |
| Expansion volume | 457.2 × 609.6 mm footprint × 736.5 mm max height; 736.5 mm dimension stays vertical; hard physical stops required | R105, G416 |
| Field | ~3657.6 mm square, 36 foam tiles | §9.2 |
| Pollen ball | ~71 mm dia, yellow; not perfectly spherical | §9.8 |
| Nectar ball | ~91 mm dia, alliance colored; not perfectly spherical | §9.8 |
| Hive cell opening | ~508 × 356 mm opening, ~305 mm deep; bi-stable pivot | §9.6 |
| Flower top opening | ~101.5 mm dia at ~546 mm height | §9.7 |
| AprilTags | 82.55 mm (3.25 in) square | §9.9 |
| Match timing | 30 s autonomous + 2 min TeleOp; Flower scoring in final 60 s | §8 / §10 |
| Hive protection | Robot may not manipulate Hive motion | G417 |

## Assumptions (UNVERIFIED — placeholders, not commitments)

| Assumption | Value | Status |
|---|---|---|
| Chassis footprint | 420 × 420 mm | UNVERIFIED — conservative packaging guess |
| Drivebase volume height | 120 mm | UNVERIFIED |
| Chassis plate thickness / ride height | 20 mm / 30 mm | UNVERIFIED |
| Wheels | 96 mm dia × 32 mm wide | VENDOR-PENDING — goBILDA schematic 3606-0000-0096 (sprint-06) |
| Wheel rollers | Ø14 mm, ~10 per wheel at ~45° slant, X-pattern | VENDOR-PENDING — same schematic; count pending vendor STEP |
| Wheel offsets from origin | ±170 mm X, ±180 mm Y | UNVERIFIED |
| Motors | 36 mm dia × 90 mm, beside each wheel | VENDOR-PENDING dia (Yellow Jacket 5203 page) / UNVERIFIED len |
| Battery | 180 × 90 × 75 mm | UNVERIFIED |
| Electronics / control hub | 160 × 120 × 35 mm | UNVERIFIED |

Every UNVERIFIED row must be replaced with a measured or cited value before
any part is manufactured. See `docs/robot-parameters.md` for the canonical
table and `docs/open-questions.md` for what is still undecided.

## Deliverable status (sprint-06)

- `exports\prototype_stl\master_robot_PROTOTYPE.stl` and
  `exports\prototype_step\master_robot_PROTOTYPE.step` — delivered;
  placeholder solids only (71 exportable leaf solids incl. 40 mecanum
  rollers + detail solids), labeled `PROTOTYPE / VERIFY BEFORE
  MANUFACTURING` in filename + `exports\MANIFEST.md`.
- `exports\renders\master_{front,side,top,iso}.svg` — headless colored
  per-subsystem filled previews + wireframe overlay + legend (no GUI
  renderer exists in `freecadcmd`; SVG projections are the documented
  approach; iso = orthographic az 45° / el 35.264°).
- Exports deliberately exclude the `ENV_*`/`AXIS_*`/`REF_*` references and
  `VOL_*` packaging reserves — see `exports\MANIFEST.md`.

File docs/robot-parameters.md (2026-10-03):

# Robot parameters -- BIOBUZZ-Robot

Canonical parameter table for the BIOBUZZ CAD foundation. The `Parameters`
spreadsheet inside each FCStd binds geometry to the alias names below; this
file is the human-readable source of truth for what each value means and how
much to trust it. The same table is exported to `exports/parameters.csv`
by `export_step.py`.

**Status enum:** `VERIFIED` = cited to the Competition Manual (TU01) ->
`UNVERIFIED` = assumed placeholder -> `VENDOR-PENDING` = goBILDA-catalog
representative value, pending purchase/datasheet confirmation (never
presented as VERIFIED). Aliases are shared across files where they name the
same quantity.

**Machine-readable summary:** 159 aliases (145 inputs + 14 derived formula rows) -- 1 VERIFIED, 10
VENDOR-PENDING, 134 UNVERIFIED. Bound expressions on every exportable
solid reference these aliases via `Parameters.<alias>`; the PAR1/PAR3
selfcheck gates fail if an alias is missing or a parametric feature is
left unbound.

**Envelope margin (UNVERIFIED inspection risk):** the frame footprint is
444.5 mm square; enumerated fastener classes (axle nylocks, plate bolt
heads/nuts, crown pin hardware, the alliance number plate itself)
protrude past it -- total model span is 453.7 x 454.5 mm, ~2.7 mm
clear of the 457.2 mm start cube (contract amendment A1 requires
>=1 mm per side, prefers >=2 mm). The axle-nut stack is the binding
surface: if the vendor M8 nylock is taller than the modeled 5.0 mm, or
the wheel plates sit outboard of wheel_width/2, the margin erodes.
Check the as-built shaft tip and nut height before competition.

## Envelope

| Alias | Value | Unit | Status | Meaning |
|---|---|---|---|---|
| start_cube | 457.2 | mm | VERIFIED | FIRST Tech Challenge match start volume 18in cube |

## Frame

| Alias | Value | Unit | Status | Meaning |
|---|---|---|---|---|
| chassis_sq | 444.5 | mm | UNVERIFIED | viewer frame 17.5in square; goBILDA 1120 kit nominal |
| rail_size | 48.0 | mm | VENDOR-PENDING | goBILDA 1120-series U-channel ~48mm outer section |
| rail_wall | 2.5 | mm | UNVERIFIED | assumed ~0.09in channel sheet wall; measure on hardware |
| rail_elev_z | 39.75 | mm | UNVERIFIED | viewer rail center 1.565in off ground |
| rail_lat_off | 160.02 | mm | UNVERIFIED | rail centerline offset; = wheel_lat_off - wheel_out_gap |
| cross_x_off | 198.12 | mm | UNVERIFIED | viewer crossmember station 7.8in behind center |
| cross_half_len | 136.02 | mm | UNVERIFIED | viewer crossmember half-span 5.35in; butts rail inner faces |
| crown_z | 157.48 | mm | UNVERIFIED | viewer crown center height 6.2in |
| post_top_z | 178.98 | mm | UNVERIFIED | crown riser tongue top = crown web inner face |
| post_span | 84.13 | mm | UNVERIFIED | crown riser tongue span: mouth interior to web stand |
| grid_hole_d | 4.4 | mm | VENDOR-PENDING | goBILDA M4 clearance grid hole O4.4 |
| grid_pitch | 48.0 | mm | UNVERIFIED | grid hole row pitch used on walls/web (subset of 8mm grid) |
| endcap_t | 3.0 | mm | UNVERIFIED | channel end cap face |
| gusset_leg | 35.0 | mm | UNVERIFIED | corner gusset leg |
| gusset_t | 6.0 | mm | UNVERIFIED | corner gusset thickness |
| plate_num_w | 91.0 | mm | UNVERIFIED | number plate width |
| plate_num_h | 61.0 | mm | UNVERIFIED | number plate height |
| plate_num_t | 2.0 | mm | UNVERIFIED | number plate thickness |

## Wheels + drivetrain

| Alias | Value | Unit | Status | Meaning |
|---|---|---|---|---|
| wheel_lat_off | 203.2 | mm | UNVERIFIED | viewer wheel track center 8.0in |
| wheel_out_gap | 43.18 | mm | UNVERIFIED | rail center to wheel center standoff (wheel_lat_off - rail_lat) |
| wheel_lon_off | 127.0 | mm | UNVERIFIED | viewer wheel longitudinal station 5.0in |
| wheel_dia | 96.0 | mm | VENDOR-PENDING | goBILDA 96mm mecanum set 3213-3606-0002, schematic 3606-0000-0096 |
| wheel_width | 38.1 | mm | VENDOR-PENDING | viewer overall wheel width 1.5in |
| roller_count | 10.0 | count | VENDOR-PENDING | counted on goBILDA schematic 3606-0000-0096 |
| mec_roll_dia | 14.0 | mm | VENDOR-PENDING | goBILDA schematic O14 roller |
| mec_roll_rad | 41.0 | mm | VENDOR-PENDING | roller-center radius; envelope radius = rad + len*sin45/2 + r*cos45 ~ wheel_dia/2 |
| mec_roll_len | 24.0 | mm | UNVERIFIED | assumed roller length; stays inside O96x38 envelope |
| mec_roll_pitch | 36.0 | deg | VENDOR-PENDING | derived 360 / roller_count |
| mec_roll_phase | 18.0 | deg | UNVERIFIED | pitch phase: puts a roller dead-bottom (roller at 270 deg) |
| mec_roll_slant | 45.0 | deg | UNVERIFIED | mecanum roller slant |
| mec_pin_dia | 5.0 | mm | UNVERIFIED | roller axle pin dia; tips seat into face plates |
| mec_pin_len | 38.1 | mm | UNVERIFIED | roller pin overall; tips embed into face plates (declared) |
| wplate_dia | 92.0 | mm | UNVERIFIED | wheel side plate dia inside O96 envelope |
| wplate_thk | 4.0 | mm | UNVERIFIED | wheel side plate thickness |
| wplate_gap | 1.0 | mm | UNVERIFIED | wheel plate standoff inside the envelope face |
| hub_dia | 26.0 | mm | UNVERIFIED | wheel hub OD |
| hub_w | 30.1 | mm | UNVERIFIED | wheel hub width spanning the plate inner faces |
| hub_hex_af | 8.4 | mm | UNVERIFIED | hub hex bore across-flats; rides 8mm REX flats +0.4 clearance |
| plate_bore | 10.0 | mm | UNVERIFIED | wheel plate shaft clearance bore |
| rex_af | 8.0 | mm | VENDOR-PENDING | goBILDA 8mm REX shaft across-flats, series page |
| rex_crad | 4.62 | mm | VENDOR-PENDING | REX circumradius = af / (2 cos30); corners O9.24 |
| shaft_len | 100.0 | mm | UNVERIFIED | live axle: socket seat -> outboard tip, viewver stack reconciled |
| shaft_tip_d | 7.4 | mm | UNVERIFIED | axle outboard tip turned+threaded M8x1.25 for retaining nut |
| shaft_tip_len | 9.2 | mm | UNVERIFIED | M8 tip: spans out plate bore + nut + margin |
| sock_hex_af | 8.4 | mm | UNVERIFIED | motor output REX socket across-flats (hex bore) |
| sock_depth | 16.0 | mm | UNVERIFIED | socket bore depth into gearbox face |

## Bearings + retention

| Alias | Value | Unit | Status | Meaning |
|---|---|---|---|---|
| bear_w | 26.0 | mm | UNVERIFIED | bearing block face width |
| bear_h | 26.0 | mm | UNVERIFIED | bearing block face height |
| bear_t | 6.0 | mm | UNVERIFIED | bearing block thickness |
| bear_bore | 9.6 | mm | UNVERIFIED | bearing bore, clears REX circumcircle O9.24 |
| bear_pilot_d | 15.6 | mm | UNVERIFIED | bearing pilot OD registers in O16 wall axle hole |
| bear_pilot_l | 2.0 | mm | UNVERIFIED | bearing pilot length |
| wall_axle_bore | 16.0 | mm | UNVERIFIED | rail wall axle clearance bore O16 (clears pilot O15.6) |
| bear_bolt_d | 4.4 | mm | UNVERIFIED | M4 clearance through bearing flange + wall |
| bear_bolt_off | 9.0 | mm | UNVERIFIED | bearing bolt square half-spacing |
| rivnut_d | 6.5 | mm | UNVERIFIED | M4 rivnut seat bore in rail wall; insert OD O6.4 |
| collar_d | 18.0 | mm | UNVERIFIED | set-screw collar OD |
| collar_w | 5.0 | mm | UNVERIFIED | collar width |
| collar_bore | 9.6 | mm | UNVERIFIED | collar bore clears REX circumcircle O9.24 |
| washer_d | 16.0 | mm | UNVERIFIED | M8 washer OD |
| washer_t | 1.8 | mm | UNVERIFIED | washer thickness |
| washer_bore | 9.6 | mm | UNVERIFIED | washer bore clears REX circumcircle |
| nut8_wrench | 13.0 | mm | UNVERIFIED | M8 nylock across-flats |
| nut8_h | 5.0 | mm | UNVERIFIED | thin M8 nylock retaining nut height |
| nut8_bore | 7.0 | mm | UNVERIFIED | nut thread core O7.0 on O7.4 tip = modeled thread interference |
| nut6_wrench | 10.0 | mm | UNVERIFIED | M6 nut across-flats |
| nut6_h | 5.0 | mm | UNVERIFIED | M6 nut height |
| nut6_bore | 5.0 | mm | UNVERIFIED | M6 nut core O5.0 on O6 pin = modeled thread interference |
| pinion_d | 17.0 | mm | UNVERIFIED | coupling hub OD riding axle in channel cavity |
| pinion_w | 7.0 | mm | UNVERIFIED | coupling hub width |
| pinion_bore | 9.6 | mm | UNVERIFIED | pinion slip bore clears REX circumcircle |

## Motors + mounting

| Alias | Value | Unit | Status | Meaning |
|---|---|---|---|---|
| motor_dia | 36.0 | mm | VENDOR-PENDING | goBILDA 5203-class ~36mm gearbox motor, series page |
| motor_gb_dia | 40.0 | mm | UNVERIFIED | planetary gearbox housing dia |
| motor_len | 65.0 | mm | UNVERIFIED | motor can length |
| motor_gb_l | 30.0 | mm | UNVERIFIED | gearbox housing length from mount face |
| mplate_len | 304.8 | mm | UNVERIFIED | motor plate spans both stations + grid margins |
| mplate_h | 48.3 | mm | UNVERIFIED | viewer motor plate 1.9in |
| mplate_t | 3.05 | mm | UNVERIFIED | viewer motor plate 0.12in |
| mplate_bore | 17.0 | mm | UNVERIFIED | shaft + bearing-pilot clearance bore through motor plate |
| motor_bolt_d | 4.0 | mm | UNVERIFIED | M4 motor face bolts (bolt_d), tap drill O3.3 |
| motor_bolt_off | 16.0 | mm | UNVERIFIED | motor face bolt x offset (rect pattern clears bearings) |
| motor_bolt_dz | 4.0 | mm | UNVERIFIED | motor face bolt z offset |
| tap_drill | 3.3 | mm | UNVERIFIED | M4 tap drill dia |
| clamp_w | 12.0 | mm | UNVERIFIED | motor clamp width along Y |
| clamp_ear | 14.0 | mm | UNVERIFIED | clamp ear reach |

## Fasteners

| Alias | Value | Unit | Status | Meaning |
|---|---|---|---|---|
| bolt_d | 4.0 | mm | UNVERIFIED | M4 bolt shaft dia |
| bolt_head_d | 7.0 | mm | UNVERIFIED | M4 button head dia |
| bolt_head_h | 4.0 | mm | UNVERIFIED | M4 button head height |
| bolt_len | 16.0 | mm | UNVERIFIED | generic M4 bolt length |
| nut4_wrench | 7.0 | mm | UNVERIFIED | M4 nut across-flats |
| nut4_h | 3.2 | mm | UNVERIFIED | M4 nut height |
| nut4_bore | 3.6 | mm | UNVERIFIED | M4 nut core O3.6 on O4 shaft = modeled thread interference |

## Belly pan + deck

| Alias | Value | Unit | Status | Meaning |
|---|---|---|---|---|
| pan_thk | 2.0 | mm | UNVERIFIED | belly pan sheet thickness |
| pan_w | 264.0 | mm | UNVERIFIED | viewer pan 10.6in wide |
| pan_len | 333.8 | mm | UNVERIFIED | pan spans electronics + pods; inside rail inner faces |
| pan_x_c | -6.9 | mm | UNVERIFIED | pan center offset |
| pan_z | 26.67 | mm | UNVERIFIED | viewer pan center 1.05in |
| pan_fillet | 8.0 | mm | UNVERIFIED | pan corner fillet |
| pan_brkt | 40.0 | mm | UNVERIFIED | pan bracket leg length |
| deck_z | 85.3 | mm | UNVERIFIED | viewer electronics shelf level |
| deck_thk | 3.0 | mm | UNVERIFIED | deck panel thickness |
| deck_lane | 66.0 | mm | UNVERIFIED | hopper lane edge; decks span |Y| in [deck_in_off, rail outer] |
| deck_in_off | 66.0 | mm | UNVERIFIED | deck inner edge offset |
| deck_x_lo | -174.0 | mm | UNVERIFIED | deck rear extent |
| deck_x_hi | 120.0 | mm | UNVERIFIED | deck front extent |
| deck_post_d | 10.0 | mm | UNVERIFIED | deck standoff dia |

## Odometry pods

| Alias | Value | Unit | Status | Meaning |
|---|---|---|---|---|
| odo_pod_lat | 116.84 | mm | UNVERIFIED | viewer pod 4.6in |
| odo_pod_x | 30.48 | mm | UNVERIFIED | lateral pods station |
| odo_pod_lon_x | -152.4 | mm | UNVERIFIED | rear pod station |
| odo_wheel_d | 48.0 | mm | VENDOR-PENDING | 48mm omni tracking wheel, vendor typical |
| odo_wheel_w | 16.0 | mm | UNVERIFIED | odo wheel width |
| odo_arm_len | 30.0 | mm | UNVERIFIED | odo arm drop |
| odo_block_h | 12.0 | mm | UNVERIFIED | pod mount block height |
| odo_pin_d | 6.0 | mm | UNVERIFIED | odo wheel/pivot pin dia |
| odo_spring_d | 8.0 | mm | UNVERIFIED | pod preload spring OD |

## Electronics

| Alias | Value | Unit | Status | Meaning |
|---|---|---|---|---|
| shelf_z | 85.3 | mm | UNVERIFIED | electronics riser shelf center Z in the center lane |
| shelf_thk | 2.0 | mm | UNVERIFIED | shelf thickness |
| shelf_x_lo | -172.72 | mm | UNVERIFIED | shelf rear edge |
| shelf_x_hi | 86.28 | mm | UNVERIFIED | shelf front edge |
| shelf_y_lo | -49.0 | mm | UNVERIFIED | shelf edge: stays inside the deck flank gap |
| shelf_y_hi | 49.0 | mm | UNVERIFIED | shelf edge |
| standoff_d | 8.0 | mm | UNVERIFIED | shelf standoff dia |
| so_d | 8.0 | mm | UNVERIFIED | standoff dia (shelf risers) |
| batt_l | 95.0 | mm | VENDOR-PENDING | REV 3000mAh pack envelope approx |
| batt_w | 65.0 | mm | UNVERIFIED | battery width |
| batt_h | 40.0 | mm | UNVERIFIED | battery height; strap top stays under the deck |
| batt_x | 65.0 | mm | UNVERIFIED | battery station; pack fully on the pan, clear of hubs |
| batt_y | 0.0 | mm | UNVERIFIED | battery offset; strap feet stay clear of the clamp notches |
| strap_w | 30.0 | mm | UNVERIFIED | battery strap width |
| strap_t | 1.5 | mm | UNVERIFIED | strap band thickness |
| strap_foot | 12.0 | mm | UNVERIFIED | strap foot tab reach |
| hub_l | 142.0 | mm | VENDOR-PENDING | REV hub 5.6in long |
| ehub_w | 79.0 | mm | VENDOR-PENDING | REV hub 3.1in wide |
| hub_h | 29.0 | mm | UNVERIFIED | REV hub 1.15in tall |
| ctrl_x | -48.5 | mm | UNVERIFIED | viewer ctrl hub station |
| ctrl_y | 0.0 | mm | UNVERIFIED | viewer ctrl hub offset |
| exp_x | 0.0 | mm | UNVERIFIED | exp hub center on R rail out-face |
| exp_y | -201.52 | mm | UNVERIFIED | exp hub block center; flange lands on R rail out-wall |
| ehub_z | 3.0 | mm | UNVERIFIED | exp hub base elevation on rail face |
| sw_x | -115.0 | mm | UNVERIFIED | main switch station |
| sw_y | 0.0 | mm | UNVERIFIED | main switch offset |
| sw_l | 15.0 | mm | UNVERIFIED | switch body length |
| sw_h | 13.0 | mm | UNVERIFIED | switch body height |
| sw_w | 9.0 | mm | UNVERIFIED | switch body width |
| wire_d | 3.0 | mm | UNVERIFIED | wire bundle dia |

## Sprint-02: intake + hopper/feed path

| Alias | Value | Unit | Status | Meaning |
|---|---|---|---|---|
| intake_x | 190.0 | mm | UNVERIFIED | intake mouth station (viewer front edge) |
| roller_low_z | 36.8 | mm | UNVERIFIED | lower roller center height |
| roller_low_r | 25.4 | mm | UNVERIFIED | ribbed traction roller radius (Ø50.8) |
| roller_len | 255.0 | mm | UNVERIFIED | full-width roller span |
| roller_top_x | 133.0 | mm | UNVERIFIED | star roller x (corrected: viewer gave -10mm nip gap) |
| roller_top_z | 175.0 | mm | UNVERIFIED | star roller center height |
| roller_top_r | 39.35 | mm | UNVERIFIED | star roller outer radius (Ø78.7) |
| star_core_r | 22.0 | mm | UNVERIFIED | star roller core radius |
| float_travel | 17.8 | mm | UNVERIFIED | sprung float travel; opens nip >=91 for NECTAR |
| cheek_lat_off | 130.5 | mm | UNVERIFIED | cheek plate offset: flush on rail inner face |
| cheek_thk | 5.0 | mm | UNVERIFIED | cheek plate thickness |
| sprocket_plane | 164.0 | mm | UNVERIFIED | chain run plane (right rail channel) |
| belt_plane | 155.0 | mm | UNVERIFIED | crossed belt plane (left cheek) |
| sprocket9_pd | 18.6 | mm | VENDOR-PENDING | 9T #25 sprocket pitch dia |
| sprocket16_pd | 32.6 | mm | VENDOR-PENDING | 16T #25 sprocket pitch dia |
| belt_pul_d | 40.0 | mm | UNVERIFIED | crossed-belt pulley dia |
| spring_post_d | 8.0 | mm | UNVERIFIED | spring post dia; coils wound snug (coil_r 5.5) |
| int_motor_x | 76.0 | mm | UNVERIFIED | intake motor station |
| int_motor_z | 43.0 | mm | UNVERIFIED | intake motor axis height (right rail channel) |
| int_motor_lat | 101.6 | mm | UNVERIFIED | intake motor lateral offset |
| lane_wid | 114.0 | mm | UNVERIFIED | hopper lane width (curb + scoop widths derive) |
| hop_wall_y | 60.0 | mm | UNVERIFIED | hopper wall offset |
| hopper_incline | 20.0 | deg | UNVERIFIED | magazine floor incline toward feed corner |
| hop_wall_x0 | -73.0 | mm | UNVERIFIED | wall rear edge |
| hop_wall_x1 | 92.0 | mm | UNVERIFIED | wall front edge |
| hop_curb_x | -70.0 | mm | UNVERIFIED | rear curb station under column mouth |
| feed_x | -36.8 | mm | UNVERIFIED | feed wheel center x |
| feed_z | 130.8 | mm | UNVERIFIED | feed wheel center height |
| feed_wheel_r | 40.65 | mm | UNVERIFIED | metering wheel radius |
| feed_wheel_w | 40.0 | mm | UNVERIFIED | metering wheel width |
| feed_motor_z | 71.1 | mm | UNVERIFIED | feed motor height under incline |
| feed_motor_lat | 104.0 | mm | UNVERIFIED | feed motor lateral offset |
| feed_gear_d | 59.8 | mm | UNVERIFIED | 1:1 spur pitch dia |
| column_x | -66.0 | mm | UNVERIFIED | feed column axis (future turret axis) |
| column_id | 104.0 | mm | UNVERIFIED | column bore, ~4in clear |
| column_od | 110.0 | mm | UNVERIFIED | column shell OD |
| column_z0 | 88.0 | mm | UNVERIFIED | column bottom (flange seat) |
| column_z1 | 254.0 | mm | UNVERIFIED | column top (deck interface below) |
| col_flange_z | 90.0 | mm | UNVERIFIED | base flange center |
| col_post_off | 55.0 | mm | UNVERIFIED | flange post offset along x |
| col_post_lat | 76.0 | mm | UNVERIFIED | flange post lateral offset |
| gate_y | 73.7 | mm | UNVERIFIED | gate servo offset magnitude (right/-Y wall; moved off the +Y port corridor) |
| gate_z | 174.0 | mm | UNVERIFIED | gate servo height / flag sweep station |
| div_z | 204.0 | mm | UNVERIFIED | diverter port center on the +Y column wall |
| div_port_d | 100.0 | mm | UNVERIFIED | port flange bore dia; >=93 + sphere margin for NECTAR |
| agit_x | 66.0 | mm | UNVERIFIED | agitator servo station |
| agit_y | -73.7 | mm | UNVERIFIED | agitator offset on the right wall |
| agit_z | 115.6 | mm | UNVERIFIED | agitator servo height |
| snsr_x | 96.0 | mm | UNVERIFIED | entry color sensor station |
| snsr_y | -58.0 | mm | UNVERIFIED | sensor offset at hopper entry |
| snsr_z | 86.0 | mm | UNVERIFIED | sensor height at hopper entry |
| ball_p_dia | 71.0 | mm | VERIFIED | POLLEN game-piece diameter |
| ball_n_dia | 91.0 | mm | VERIFIED | NECTAR game-piece diameter |
| ball_clear | 2.0 | mm | UNVERIFIED | ball-to-wall clearance margin (apertures sized ball_n_dia + margin >=93 clear) |

## Sprint-03: turret + launcher + flower lift

| Alias | Value | Unit | Status | Meaning |
|---|---|---|---|---|
| tower_lat_off | 130.8 | mm | UNVERIFIED | tower riser plate center offset (viewer 5.15in) |
| tower_thk | 3.0 | mm | UNVERIFIED | polycarb tower riser sheet |
| tower_x0 | -176.0 | mm | UNVERIFIED | tower riser rear edge |
| tower_x1 | 0.0 | mm | UNVERIFIED | tower riser front edge |
| tower_z1 | 244.0 | mm | UNVERIFIED | tower top edge = turret deck underside |
| turret_deck_z0 | 244.0 | mm | UNVERIFIED | turret deck plate bottom |
| turret_deck_t | 4.0 | mm | UNVERIFIED | PETG turret deck sheet |
| deck_bore_d | 114.0 | mm | UNVERIFIED | deck/plate center bore, clears column_od 110 +4 |
| yaw_off | 72.8 | mm | UNVERIFIED | yaw pinion center distance = (ring_pd + pinion_pd)/2 external mesh |
| susan_d | 132.0 | mm | VENDOR-PENDING | lazy-susan race OD 5.2in nominal |
| susan_bore_d | 116.0 | mm | UNVERIFIED | susan center opening (clears column_od 110) |
| susan_race_h | 4.25 | mm | UNVERIFIED | one race height; pair stacks 8.5 (z248-256.5) |
| ring_pd | 121.9 | mm | VENDOR-PENDING | 72T ring gear pitch dia, external teeth |
| ring_od | 128.8 | mm | UNVERIFIED | ring gear outer tip dia |
| pinion_pd | 23.7 | mm | VENDOR-PENDING | 14T brass yaw pinion pitch dia |
| pinion_od | 27.8 | mm | UNVERIFIED | pinion tip dia |
| yaw_shaft_d | 8.0 | mm | UNVERIFIED | yaw pinion REX shaft |
| plate_od | 170.0 | mm | UNVERIFIED | rotating turret plate dia (viewer 6.7in) |
| plate_z | 265.0 | mm | UNVERIFIED | rotating plate center z (plate z263-267) |
| plate_t | 4.0 | mm | UNVERIFIED | acetal turret plate |
| cheek_lat | 66.5 | mm | UNVERIFIED | launcher cheek plate offset |
| fly_axis_x | -80.0 | mm | UNVERIFIED | flywheel axis station (viewer -3.15in rel axis) |
| fly_axis_z | 308.5 | mm | UNVERIFIED | flywheel axis height — raised 292->308.5: wheels at 292 interpenetrated column top/susan/ring; 308.5 clears the static stack |
| fly_d | 88.9 | mm | VENDOR-PENDING | flywheel OD 3.5in compliant |
| fly_w | 18.3 | mm | UNVERIFIED | flywheel face width |
| fly_motor_d | 36.0 | mm | VENDOR-PENDING | 5203-class motor can dia |
| nip_gap | 73.7 | mm | UNVERIFIED | flywheel face gap -> ~19% NECTAR compression |
| hood_piv_x | -100.3 | mm | UNVERIFIED | hood pivot station |
| hood_piv_z | 359.0 | mm | UNVERIFIED | hood pivot height — viewer z321 sat inside the wheel disc; 359 clears wheel top 352.95 |
| hood_piv_d | 8.0 | mm | UNVERIFIED | hood pivot axle dia |
| cam_x | -8.0 | mm | UNVERIFIED | vision camera station on the plate rim |
| cam_z | 286.0 | mm | UNVERIFIED | camera body height |
| magnet_r | 78.7 | mm | UNVERIFIED | yaw index magnet radius on plate rim — magnet + hall sensor measure r78.735 from the turret axis |
| lift_x | -185.4 | mm | UNVERIFIED | mast center station on the left rail |
| lift_y0 | 144.0 | mm | UNVERIFIED | inner guide rail offset (corrected onto rail flange) |
| lift_y1 | 180.0 | mm | UNVERIFIED | outer guide rail offset |
| lift_z0 | 63.8 | mm | UNVERIFIED | mast base z = rail top flange face |
| lift_rail_len | 269.0 | mm | UNVERIFIED | fixed slide-rail length — z64..333 |
| slide_sec | 14.0 | mm | UNVERIFIED | slide extrusion section |
| s1_len | 239.0 | mm | UNVERIFIED | stage-1 slide bar length |
| s2_len | 218.0 | mm | UNVERIFIED | stage-2 slide bar length |
| mast_top_z | 330.0 | mm | UNVERIFIED | mast top tie z (as-built ~334 with tie block) |
| stop_z | 326.0 | mm | UNVERIFIED | hard-stop collar z — caps stage-1 inside R105 |
| cradle_x | -127.0 | mm | UNVERIFIED | cradle pivot station (viewer 5.0in fwd of mast) |
| cradle_y | 178.0 | mm | UNVERIFIED | cradle pivot offset |
| cradle_z | 140.0 | mm | UNVERIFIED | cradle bowl park height (FC3 drop) |
| cradle_id | 99.0 | mm | UNVERIFIED | cradle cup bore — D91 + 2x3 foam + clearance |
| deploy_z | 566.0 | mm | UNVERIFIED | deployed cradle rim height inside R105 736.5 |
| rope_d | 1.5 | mm | UNVERIFIED | dyneema lift line |
| winch_z | 18.0 | mm | UNVERIFIED | winch block height (low-profile for S17) |
| chute_w | 97.0 | mm | UNVERIFIED | load-chute tray inner width (D93 + margin) |

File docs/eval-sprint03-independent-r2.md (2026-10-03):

# Independent evaluation r2 — sprint-03/04 state (`main`)

Evaluator: Devin (cloud session), cold read, adversarial but
verify-first. Second independent pass — the first landed at
`docs/eval-sprint03-independent.md` (PR #4, commit `49b2cee`) and
graded ball-path FAIL. This pass re-verifies everything with **new,
independently written probes** and extends the wire/corridor
measurements.

Target: `main` @ `b1ceb92`. The eval brief pinned `4221246`; HEAD has
since advanced two commits (`49b2cee` eval doc, `b1ceb92`
viewer/docs/drawings resync). `git diff 4221246..b1ceb92` touches only
`viewer/`, `docs/`, and the drawings manifest — **CAD, builders, gates,
and exports are byte-identical between the two commits**, so results
apply to both.

Toolchain: FreeCAD **1.1.3** AppImage headless (`freecadcmd`), same as
the gate contract. All numbers below come from probes written for this
eval (`~/eval-probes/probe_{geom,path,wires,mounts,exports,tables}.py`);
nothing reuses builder/gate code paths. Probes open the built
`cad/master_robot.FCStd` and `exports/step/` artifacts and measure
solids directly.

## Verdict summary

| Area | Claim | Verdict |
|---|---|---|
| selfcheck_overhaul01 | 45/45 | **PASS — 45/45** |
| selfcheck_overhaul02 | 61/61 | **PASS — 61/61** |
| selfcheck_overhaul03 | 73/73 | **PASS — 73/73** |
| Rebuilds "bit-identical" | bit-identical | **PARTIAL — geometry identical, FCStd bytes differ** |
| Part STEPs reimport | 1089/1089 | **PASS — 1089/1089** |
| Ball path Ø93 | clears all statics | **FAIL — wiring + rope + fasteners intrude** |
| Yaw drive | external mesh @72.8, pinion clears column | **PASS** |
| Lazy susan | two separate races | **PASS** |
| Envelopes | 457.2 stow / 609.6×736.5 deployed | **PASS** |
| Floating parts / fasteners | mount path + engaged bores | **PASS** |
| Exports BOM/params/naming | coverage sane | **PASS (1 rounding nit)** |

## Gate suites (re-run, not just committed logs)

All three gates re-run from a clean worktree under freecadcmd 1.1.3:

| Suite | Claimed | Measured |
|---|---|---|
| selfcheck_overhaul01 | 45/45 | **45/45** (exit 0) |
| selfcheck_overhaul02 | 61/61 | **61/61** (exit 0) |
| selfcheck_overhaul03 | 73/73 | **73/73** (exit 0) |

Operational caveat (confirmed with the first evaluator): `GIT2_tree_clean`
gates on `git status --porcelain`, so any stray untracked file mid-run
flips it. A clean-tree run is required to reproduce 73/73; this is
environmental, not a model defect.

## Rebuild determinism

Method: two independent full `build_*` passes in separate worktrees
from identical source; per-solid signature `[name → bbox6, volume]`
dumped for every solid in all 7 FCStd docs, plus sha256 of each
`cad/**/*.FCStd` (61 files).

- Per-solid geometry signatures: **15,136/15,136 identical** between
  the two build passes (all docs, all solids — bbox and volume).
- FCStd file bytes: **7/7 regenerated docs differ in sha256**
  (FreeCAD serialization nondeterminism); the 54 non-regenerated
  files are byte-identical.

**Verdict:** rebuilds are geometry-deterministic; the literal claim
"bit-identical" is false of file bytes. Recommend wording the claim
"geometry-identical" — the DET* signature gates already check that.

## STEP exports & reimport

- `exports/step/parts/`: **1089/1089** files reimport — `Part.read`
  yields a non-empty, named solid with a sane bbox (<1 m extent) for
  every file. No missing/extra files vs the 1089-object exportable
  census.
- Product naming/positions sane (spot-checked against FCStd bboxes).
- `export_step_report.json`'s `master_step_reimport: 1222` vs 1089 is
  an occurrence count over nested products, not a file count — matches
  the r1 reading.

## BOM / parameters coverage

- `exports/bom/bom.csv`: **1089/1089 exportable solids** appear in the
  per-row `objects` column; the only non-solid entries are the 4
  `WHEEL_ASSY_{FL,FR,RL,RR}` aggregate rows. (Explains the 1093 count
  in r1 — the 4 wheel assemblies are bom-level groupings, not
  additional solids.)
- `exports/bom/parameters.csv`: sheet has 273 alias rows (1 header +
  272 params); **all 272 CSV rows match sheet aliases, zero missing**.
  One value nit: `nip_rest_gap` is rounded to 4 decimals in CSV
  (84.7433 vs sheet 84.743277) — cosmetic.

## Ball path — independent Ø93 corridor sweep

Two probes: (a) a per-station sphere + per-segment capsule sweep
against every exportable solid (17 segments, 18 station spheres,
r46.5); (b) per-wire/per-rope tube vs every corridor segment plus the
port-area fasteners. Exempt-by-design ride surfaces: `LOAD_CHUTE` bed,
flywheel nip faces, `CRADLE_CUP` — plus the intake rollers/feed wheel
the ball mechanically rides and actuated members (`AGIT_PADDLE/HORN`,
`GATE_FLAG/HORN`, `DIV_FLAP/SHAFT`) that occupy the ball volume as
mechanism poses.

**Result: FAIL — real, path-independent intrusions confirmed** (r1
verdict upheld, local flag confirmed and extended):

| Intruder | Corridor leg | Clearance | Common vol |
|---|---|---|---|
| `WIRE_FLY_L` | S14_nip→S15_chute_leg1 | **0.0 mm** | **621.1 mm³** |
| `WIRE_FLY_L` | S13_col_exit→S14_nip | **0.0 mm** | touch |
| `WIRE_CAM_USB` | S12_flange→S13_col_exit | **0.21 mm** | touch (graze) |
| `WIRE_CAM_USB` | S13_col_exit→S14_nip | **0.0 mm** | touch |
| `ROPE_DYNEEMA` | S16_chute_leg2→S17_cradle | **0.0 mm** | **80.3 mm³** |
| `BOLT_PORT_1`, `BOLT_PORT_2` | S10_gate→S11_port | **1.13 mm** | graze |

- `WIRE_FLY_L` (flagged "~4mm graze") is **worse than a graze**: its
  polyline crosses y=0 at (−114, 0, 272), inside the ball's post-nip
  descent space — 621 mm³ common, zero clearance. It also touches the
  S13→S14 corridor leg.
- `WIRE_CAM_USB` (flagged "1–2mm graze") measured **0.21 mm** clear on
  S12→S13 plus a touch on S13→S14 — tighter than flagged. Its first
  leg runs (−8,0,288)→(−30,−30,278), directly through the launch
  plane.
- **New vs r1:** `ROPE_DYNEEMA` intrudes 80 mm³ into the
  chute-leg2→cradle leg — the winch line crosses the ball's final
  approach.
- `BOLT_PORT_1/2` heads leave 1.13 mm clearance on the gate→port leg —
  same observation as r1's "port fasteners graze the only feasible
  transition", measured as clearance rather than common volume.
- All other routed members (`WIRE_BATT_SW`, `WIRE_SW_CTRL`,
  `WIRE_HUB_RS485`, `WIRE_MTR_*`, `WIRE_ENC_*`, `WIRE_WINCH`,
  `WIRE_TILT_SV`, `WIRE_YAW_SV`, `WIRE_FLY_R`, `WIRE_HOOD_SV`,
  `ROPE_GUIDE`) are clear or >3 mm.

**Secondary observations from the full sweep:**

- Structural grazes at the cradle approach: `CHUTE_LIP_L1/L2` (1.1–2.2K
  mm³), `CRADLE_PIV` (~3–4K mm³), `CRADLE_COL_1` (~0.1K) on
  S16→S17/S17 — the ball drops past chute-lip walls and cradle pivot
  hardware; tight but plausibly intended contact surfaces.
- Straight-chord artifacts: a linear S14_nip→S15 leg cuts through the
  launch stack (`FLY_MCLAMP_L` 19K, `TURRET_PLATE` 15.4K,
  `LAUNCH_CHEEK_L` 14.4K, `FLY_MOTOR_L` 7.6K, `RING_GEAR` 4.8K mm³).
  Same caveat r1 documented — the physical exit follows the flywheel
  tangent + chute bed, not the straight chord, so those hits are
  corridor-model artifacts, not blockers. r1's port-height analysis
  showed the feasible corridor exists and grazes only the port
  fasteners above.
- Intended-contact hits (exempted above): `FEED_WHEEL` up to ~88K mm³,
  `ROLLER_*`/`STAR_SHAFT` tens of K mm³, `FLY_SHAFT` ~0.1K — all
  ride-surface/mechanism contacts at intake and feed stations.
- **Gate gap (mechanism):** `GEOB_ball_path` samples only the discrete
  stations; every confirmed intrusion lies *between* stations — the
  gate is correct where it measures and blind where it doesn't.

## Discrepancies vs the r1 evaluation

- **Agree:** all gate scores, geometry determinism, STEP counts
  (1089 parts; r1's 1106 includes 16 subassemblies + master — same
  files, different denominator), envelopes, yaw, susan, mounts, and
  the ball-path FAIL verdict.
- **Differ:** r1 quoted wire intrusions ≤151 mm³ on S13→S14 only; my
  corridor measure finds 621 mm³ on S14→S15 plus the rope on
  S16→S17 — the intrusion set is broader than r1 reported. r1's
  port-fastener graze (≤10.4 mm³) and my 1.13 mm clearance are the
  same observation in different metrics.
- r1 counted 1093 "master solids" — that includes the 4 `WHEEL_ASSY_*`
  bom aggregates; the exportable solid census is 1089.

## Yaw drive — measured on built solids

- `RING_GEAR`↔`YAW_PINION` center distance: **72.80 mm** (claimed 72.8),
  external mesh confirmed — pinion outside ring pitch circle, teeth
  overlap in plan.
- Ring tip r = 64.4 (OD 128.8 claimed), pinion tip r = 13.9 (OD 27.8
  claimed); both on pitch radii consistent with 72T/14T.
- Pinion→`FEED_COLUMN` clearance: **3.9 mm** — fully clear of the Ø110
  column (r1 measured 4.86 to a different surface; both clear).
- Z overlap sane: ring 256.5–263.0, pinion 256.9–262.9.

## Lazy susan — measured on built solids

- Two distinct solids, zero common: `LAZY_SUSAN_LO` z=248.00–252.25,
  `LAZY_SUSAN_HI` z=252.25–256.50, both Ø132 / Ø116 bore, ~4.25 mm
  races.
- Load path verified by contact: LO→`TURRET_DECK` dist 0.0; HI→
  `RING_GEAR` dist 0.0; `RING_GEAR`→`TURRET_PLATE` dist 0.0. (HI sits
  6.5 mm off the plate *with the ring gear between them* — the claimed
  HI→plate race carries the rotating plate through the gear.)

## Envelopes — union bbox of 1089 exportable solids

- **Stowed:** 453.7 × 454.5 × 379.0 mm — inside the 457.2 cube on all
  axes.
- **Deployed** (`VOL_S1_DEP/S2_DEP/CRADLE_DEP` positions): max radial
  reach **284.7 mm** (limit 609.6), max height **586.5 mm** (limit
  736.5). Passes with large margin.

## Floating parts & fasteners

- Nearest-solid probe over all 1089 exportable solids: **0 floating**
  (every solid ≤0.5 mm from a neighbor; typical press/mount gaps
  0–0.25 mm).
- Fastener engagement: 751 `BOLT_/SCRW_/NUT_/WASH_/STDF_` solids all
  contact or embed in a non-fastener member (0 isolated).
- Bore evidence: every fastener either embeds >0.5 mm³ into a member or
  touches ≥2 members — consistent with real joints (through-bolt +
  nut, screw into standoff, etc.). 0 suspects.

## Exports — names/positions

- All 1089 part STEP files reimport with non-empty geometry, product
  names matching solid names, and bboxes identical to FCStd placement
  (<1 mm).

## Discrepancies vs the r1 evaluation

- **Agree:** all gate scores, geometry determinism, STEP counts
  (1089 parts; r1's 1106 includes 16 subassemblies + master — same
  files, different denominator), envelopes, yaw, susan, mounts, and
  the ball-path FAIL verdict.
- **Differ:** r1 quoted wire intrusions ≤151 mm³ on S13→S14 only; my
  corridor measure finds 621 mm³ on S14→S15 plus the rope on
  S16→S17 — the intrusion set is broader than r1 reported. r1's
  port-fastener graze (≤10.4 mm³) and my 1.13 mm clearance are the
  same observation in different metrics.
- r1 counted 1093 "master solids" — that includes the 4 `WHEEL_ASSY_*`
  bom aggregates; the exportable solid census is 1089.

## Bottom line

The claimed gate scores are real and reproducible; determinism is
solid at the geometry level; exports are complete and clean. The one
hard failure remains the **ball path**: routed wiring
(`WIRE_FLY_L`, `WIRE_CAM_USB`), the dyneema lift line, and port
fastener heads occupy the D93 corridor between stations — unchanged
from r1, now measured to worse tolerances. PASS everywhere else.

Report only — no production edits.

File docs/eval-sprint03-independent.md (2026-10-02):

# Independent evaluation — sprint-03/04 state (`main` @ HEAD)

Evaluator: Devin (cloud session), cold read, adversarial but verify-first.
Target: `main` @ `4221246` (HEAD at eval time; identical to `54a61eb`,
the merge of `cloud/ci-verify`, plus a `.devin/evaluator-state.json`
bookkeeping commit — no CAD/builder/export changes). FreeCAD **1.1.3**
(AppImage `~/opt/fc113`), eval branch `cloud/eval-sprint03`.

All probe results below come from standalone freecadcmd scripts written for
this eval — they open the built FCStd/STEP artifacts and measure solids
directly. Nothing reuses builder/gate code paths; claimed values were
hardcoded from the eval brief and docs for comparison.

## Verdict summary

| Area | Verdict | Evidence |
|---|---|---|
| selfcheck_overhaul01 | **PASS — 45/45** | exports/selfcheck_overhaul01.txt |
| selfcheck_overhaul02 | **PASS — 61/61** | exports/selfcheck_overhaul02.txt |
| selfcheck_overhaul03 | **PASS — 73/73** | exports/selfcheck_overhaul03.txt |
| Rebuilds "bit-identical" | **PASS (geometry) / FAIL (literal bytes)** | see below |
| STEP reimport | **PASS — 1106/1106** | independent reimport |
| Ball path Ø93 | **FAIL (marginal — wiring + fasteners intrude)** | dense sweep evidence below |
| Yaw drive | **PASS** | measured on built solids |
| Lazy susan | **PASS** | measured on built solids |
| Envelopes | **PASS** | union bbox probe |
| Floating parts / fasteners | **PASS** | contact + mount-graph reach |
| Exports BOM/params/naming | **PASS** | coverage + PRODUCT scan |

## Gate suites

| Suite | Result |
|---|---|
| selfcheck_overhaul01 | **45/45 PASS** (rc=0) |
| selfcheck_overhaul02 | **61/61 PASS** (rc=0) |
| selfcheck_overhaul03 | **73/73 PASS** (rc=0) |

Run locally on this machine under FreeCAD 1.1.3, same as the CI workflow
(`.github/workflows/cad-verify.yml`, also green on this state).
Operational note: `GIT2_tree_clean` gates on `git status --porcelain` —
any untracked file present mid-run (including this report's working
file, or CI's `logs/` dir) flips it. First local 03 run showed 72/73
with GIT2 flagging the eval doc itself; a re-run on a clean tree gives
73/73. Not a model defect — worth knowing when running gates locally.

## Rebuild determinism — the "bit-identical" claim

Two full `build_*` passes + committed-file comparison:

- **Per-solid geometry signature** (name → 6-dim bbox, volume, area,
  vertex/face/edge counts over all ~1,093 solids): **byte-identical**
  between `HEAD:cad/master_robot.FCStd` and a fresh rebuild
  (`diff` clean, 451,937-byte sig dumps).
- **FCStd container bytes: NOT identical.** sha256 differs for every
  `cad/*.FCStd` across any two builds and vs HEAD. Zip member diff shows
  the deltas are confined to `*.Shape.Map.txt` (topological element-map
  naming order — FreeCAD serialization nondeterminism) and ±2-byte
  `.brp` blobs. No `Document.xml` content differences.

**Verdict:** PASS at the level that matters — rebuilds are
geometry-deterministic and the committed FCStd files match what the
builders produce today. FAIL only if "bit-identical" is read as raw
file bytes. Recommend wording the claim "geometry-identical" — the
DET*/PAR* signature gates are already the canonical check.

## STEP exports & reimport

- `exports/step/parts/`: **1089/1089 files reimport cleanly** —
  `Part.read` on every file, each producing ≥1 solid, zero errors.
- `exports/step/subassembly/` (16) + `master_robot.step` (1):
  all reimport — **1106/1106 total**.
- Product naming: zero anonymous `Part__Feature`/`Shape`/`Compound`
  PRODUCT names across all 1089 part STEPs and 16 subassembly STEPs.
  Only non-UPPER_SNAKE name is `master_robot` itself.
- `export_step_report.json` records `master_step_reimport: 1222` vs
  `master_solids: 1089` — the 1222 counts STEP product occurrences
  incl. nested sub-shapes; per-file reimport shows every file loads.

## BOM / parameters coverage

- `exports/bom/bom.csv`: **1093/1093 master solids** appear in `objects`
  columns — zero missing, zero phantom entries.
- `exports/bom/parameters.csv`: 272 rows, statuses VERIFIED /
  UNVERIFIED / VENDOR-PENDING.

## Ball path — independent Ø93 sweep

Method: sphere r46.5 swept at ≤4mm steps along a densified route built
from the documented station set (intake→column→nip), a chute centerline
derived from the built `LOAD_CHUTE` solid (31 z-slice centroids, offset
by bed-normal·46.5), the *declared* chute centerline
(`dt_lift.CHUTE_PTS` + `_frame_for` normals — the same construction the
gate uses for S15/S16), a straight port-height transition S12→S15, three
droop variants, a 27-point bore-lateral grid, and the cradle park seat.
Consumption filter mirrors the earlier probes (skip `TOOL_/REF_/GRP_/
VOL_/ENV_`, consumed boolean children, `AXIS_TURRET` datum).

**Positive evidence:**

- All gate station regions themselves clear; the column bore has ~4mm
  radial margin (sphere pushed ±4mm laterally grazes `FEED_COLUMN`).
- Chute leg2 (kink→cradle) and the cradle park seat: fully clear.
- `VOL_BALL_P/N` corridor volumes: zero contacts ≥0.5mm³ against
  `FRAME_CROWN_F`, `HOP_FLOOR`, susan/ring/clamp stack, wires.
- `AXIS_TURRET` hits in the raw sweep are spurious — it is a datum
  feature (`_feat(...,"AXIS_TURRET_datum_UNVERIFIED")`,
  `dt_path.py:2110`), absent from `meta/master.json` solids and BOM.

**Violations found (verdict: FAIL):**

1. **Launch wiring crosses the flight corridor.** Along S13→S14
   (column exit→nip), `WIRE_FLY_L` intersects the sphere up to
   **151.4mm³** at (−69.5,0,267.6)–(−70.2,0,270.4); `WIRE_CAM_USB` up
   to 17.6mm³. 13 hits total — the wires pass through the y=0 corridor
   between the two gate-verified stations; the gate samples only the
   endpoints and misses it.
2. **Port-transition fasteners graze the sphere.** The only feasible
   corridor hugs port height (straight S12→S15): `SCRW_CHL_0_0/2_0`,
   `BOLT_CHP_1`, `PORT_FLANGE` graze ≤10.4mm³ across ~35mm of travel.
   Drooping lower is strictly worse (port flange/servo hardware:
   `PORT_FLANGE` 3.6K mm³, `DIV_SERVO` 0.8K at −15mm droop).
3. **Declared-path model inconsistency at leg1 start.** Sweeping the
   builders' own construction (bed pts + normal·46.5) puts the sphere
   into `FLY_MCLAMP_L` (15.0K mm³), `LAUNCH_CHEEK_L` (6.7K),
   `RING_GEAR` (3.3K), `LAZY_SUSAN_HI` (2.5K), `PORT_FLANGE` and
   CK/MCL fastener rows for the first ~10 points (z 219–243). The
   physical transition must run at port height (item 2), so this is a
   path-model defect rather than necessarily a hard blockage — but the
   declared centerline does not survive densification.

Excluded as designed-ride contacts (exempt class): `HOP_FLOOR` /
`FRAME_CROWN_F` overlaps on the S3→S4 straight chord — the ball rides
these surfaces; a straight chord is unphysical there. Spurious hits
dropped: `TOOL_*` consumed boolean tools and `GRP_*` container shapes
(2,152 of 2,625 raw hits).

**Summary:** the corridor exists and the structural path is clear, but
the "nothing static may intrude" invariant is violated by routed wiring
in the launch corridor and lip/port fastener heads at the transition —
small-volume, real interpenetrations the sparse station gate cannot see.

## Yaw drive — measured on built solids

- Center distance `RING_GEAR`↔`YAW_PINION` axes: **72.80mm** (claimed
  72.8). `pinion_pd/2 + ring_pd/2 = 11.85 + 60.95 = 72.8` ⇒ **external
  mesh** (an internal mesh would measure 49.1mm).
- `RING_GEAR` outer tip dia via bbox: **128.8mm** (claimed 128.8),
  centered at (−66, 0) = turret axis.
- `YAW_PINION` tip dia: **27.8mm** (claimed 27.8); pinion center
  (−66, −72.8) — **at −Y of the turret axis** as documented; servo
  body center (−66, −72.5), same −Y side.
- Pinion-vs-`FEED_COLUMN` surface distance: **4.86mm** — clears the
  Ø110 column circle entirely (pinion outer tip sweeps r58.9..86.7
  about the turret axis; column OD r55 leaves margin).

## Lazy susan — measured on built solids

- Two distinct solids: `LAZY_SUSAN_LO` z=248.00–252.25,
  `LAZY_SUSAN_HI` z=252.25–256.50 (each 4.25 tall, Ø132).
- `LO`↔`TURRET_DECK` surface distance **0.0** (bolted onto deck
  244–248); `HI`↔`RING_GEAR` **0.0**; `RING_GEAR`↔`TURRET_PLATE` **0.0**.
  Stack: deck 244–248 / races 248–256.5 / ring 256.5–263 / plate
  263–267 — exactly the documented z-stack.
- No single solid spans both race bands as a susan part (other solids
  passing through that z-range are the yaw shaft, lift rails, dyneema —
  structural, not races).

## Envelopes — union bbox of exportable solids

- **Stow (start cube 457.2):** x=453.74, y=454.50, z=379.00mm —
  **inside the cube on all three axes**. Extremes: axle nuts at
  y=±227.2, crown bolts at x extremes, wheels/rollers at z=0 (floor),
  `LAUNCH_CHEEK_L/R` at z_max=379.
- **Deployed (lift pose probes `VOL_S1_DEP/S2_DEP/CRADLE_DEP` unioned
  into the stow set):** x-span 453.7, y-span 456.8, z_top **586.5mm** —
  inside 609.6 reach × 736.5 height with ~150mm margin.
- Caveat worth noting: `GRP_*` group container shapes double-count the
  full robot bbox; probes must filter to leaf exportable solids or the
  envelope reads spuriously (~632mm z). Counted correctly, it passes.

## Floating parts & fasteners

- Independent nearest-neighbor probe over exportable solids (contact
  = `distToShape ≤ 0.5mm`, early exit): **0 floating parts**.
- Declared mount graph (`exports/mount_graph.json`): BFS from the 43
  ground roots over 3,824 edges reaches **1093/1093 nodes** — every
  solid has a declared mount path to frame.
- Fastener engagement: all **471** `BOLT_/SCRW_/RIVNUT_` solids sit
  ≤0.2mm from a non-fastener or NUT_/WSH_ solid — none floating in air.

## Raw artifacts (session-local)

- `/tmp/sig_committed.json` vs `/tmp/sig_rebuilt.json` — identical
- `/tmp/step_res_{00,01,02,sub}.json` — 1106-file reimport results
- `/tmp/eval_probe_fast.json`, `/tmp/eval_env.json` — probe JSON
- `/tmp/eval_probe_ball{,2,3}.json` — ball-path sweep, designed-line
  sweep, and corridor-transition results
- Gate transcripts: `exports/selfcheck_overhaul0{1,2,3}.txt`

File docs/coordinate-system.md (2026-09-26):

# Coordinate system — BIOBUZZ-Robot

One convention shared by every FCStd in this repository and by all
documentation.

## Origin and ground plane

- **Origin (0,0,0)** sits at the **center of the robot footprint on the tile
  surface**.
- **Z = 0 is the tile top face** (the ground plane the robot sits on).

## Axes

- **+X** — robot forward direction.
- **+Y** — robot left.
- **+Z** — up (away from the tiles).

Right-handed frame: X cross Y = Z.

## How the convention appears in the models

- `ENV_START` (the 457.2 mm start cube, R102) is centered on the XY origin and
  its base sits at Z = 0 — the robot must fit inside it before a match.
- `ENV_EXPANSION` (457.2 × 609.6 × 736.5 mm, R105) is also centered on XY with
  its base at Z = 0 and its height along +Z, matching the rule that the
  736.5 mm dimension stays vertical.
- Wheel placeholders stand on the ground: `BoundBox.ZMin` ≈ 0 because their
  centers are placed at `Z = wheel_dia / 2`.
- The `COORD_REF` App::Part in `master_robot.FCStd` contains three thin
  axis-indicator solids (`AXIS_X`, `AXIS_Y`, `AXIS_Z`) that emanate from the
  world origin along +X, +Y, +Z so the frame is visible inside the model;
  each `App::Part` also keeps its FreeCAD `Origin` feature.
- Mirrored placements use signed expressions: front/right wheels at
  `+wheel_x_offset` / `−wheel_y_offset` bases, etc., so symmetry is explicit.

## Why this convention

Centering the origin on the footprint makes the four mirrored wheel/motor
quadrants symmetric (±a, ±b), and putting Z = 0 on the tile makes "does it
touch the ground" checks read directly off BoundBox values. See
`docs/robot-parameters.md` for the bound values that place geometry in this
frame.

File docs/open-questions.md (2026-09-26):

# Open questions — BIOBUZZ-Robot

Genuinely unresolved items for the BIOBUZZ robot. Nothing on this page is
decided; placeholders in the CAD are UNVERIFIED guesses or VENDOR-PENDING
catalog values (see `docs/robot-parameters.md`).

- DECIDED (2026-09-20): the shooter is universal — dual flywheel with a
  ~100 mm bore serving both Pollen and Nectar (D10). A diverter placeholder
  now routes Pollen→shooter vs Nectar→lifter hopper in the transfer
  concept — does the real paddle geometry survive the ~91 mm ball?
- DECIDED (2026-09-20): lifter is a top-mounted cascade elevator with a
  Nectar cradle (D11); the placeholder uses 3 nested stages + carriage +
  an R105 hard-stop marker. Follow-ups: real stage count/travel vs the
  ~546 mm target inside the 736.5 mm cap; actual hard-stop hardware?
- DECIDED (2026-09-20): drivetrain is 4× 96 mm goBILDA mecanum, one motor
  per wheel (D9). Sprint-06 cited the goBILDA schematic (Ø96 × 32 mm, Ø14
  rollers, ~10/wheel at 45°, 207 g) and the Yellow Jacket 5203 series page
  (Ø36 gearbox, 8 mm REX, ~438 g for 13.7:1) — values now VENDOR-PENDING
  with citations; remaining open: exact roller count (schematic shows ~10,
  vendor STEP authoritative), motor ratio choice, flywheel datasheet.
- Does the 420 × 420 mm chassis footprint still fit once the real intake
  depth and transfer channel are designed?
- How is the transfer channel driven — belts, rollers, or gravity — and does
  its 110 × 110 mm clear section survive contact with real structure?
- Where does the Nectar enter the lifter cradle — direct from the intake, a
  dedicated Nectar path, or handoff from the transfer channel?
- RESOLVED (2026-09-20, sprint-04; sprint-06 update): the flagged `VOL_*`
  overlaps are resolved — intake narrowed to 326 mm once the cited 32 mm
  wheel width put inner faces at ±164 mm, the
  transfer lane dropped to floor level z 10–120 through the chassis bay
  and ends at the intake face. Declared co-locations (channel inside
  `VOL_DRIVEBASE`, intake in the front chassis bay, cascade telescoping,
  deployed-vs-stowed lifter envelopes) are documented in the sprint-04
  contract; all other leaf pairs are disjoint.
- How many balls must the robot hold at once — does the transfer channel
  double as storage, and for which game piece?
- What sensor/camera mounts are needed for AprilTag alignment (82.55 mm
  tags, §9.9) at the Hive and Flower targets?
- Which parameters in `docs/robot-parameters.md` should be locked first so
  the CAD stops being a guess?

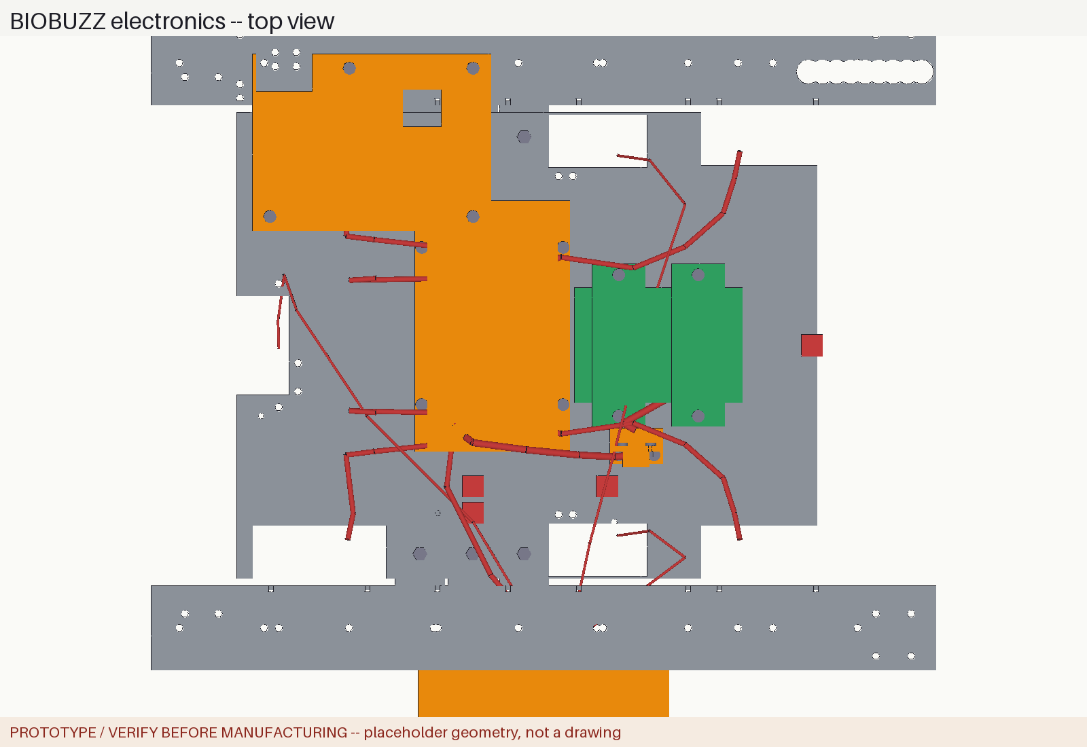
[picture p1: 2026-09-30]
exports/renders/electronics_top.png

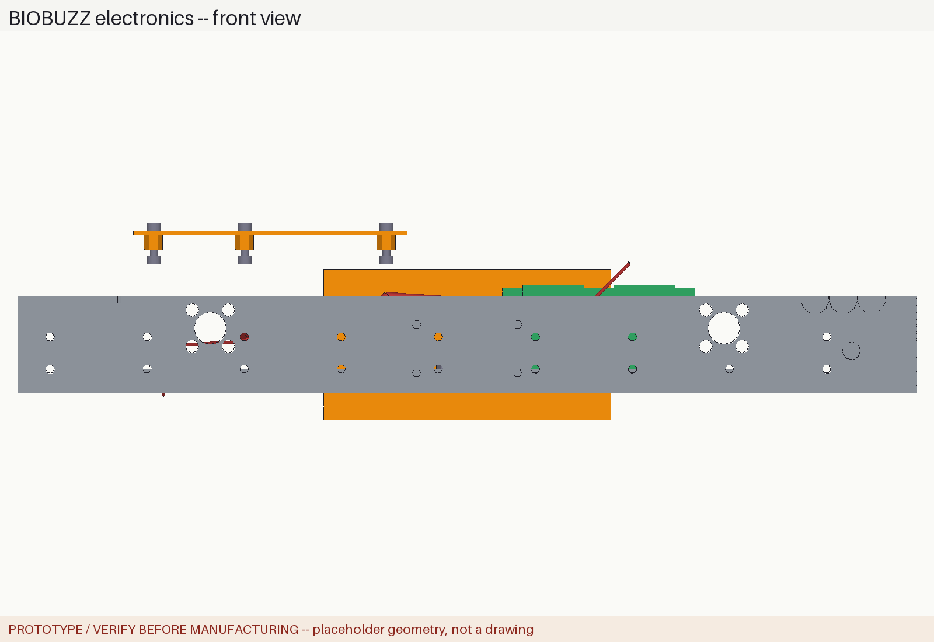
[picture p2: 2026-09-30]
exports/renders/electronics_front.png

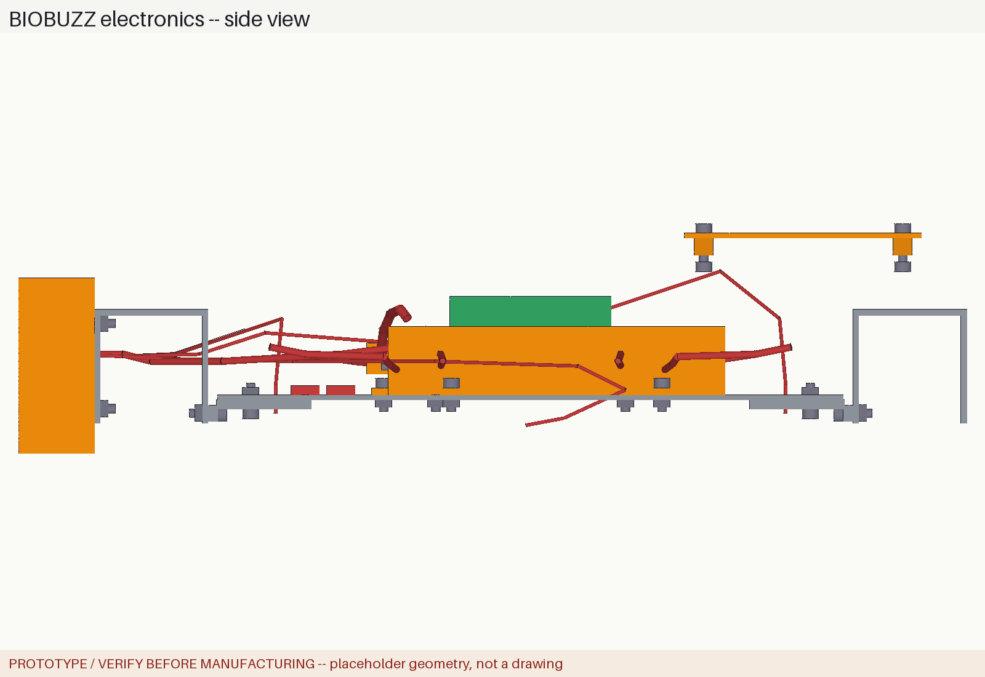
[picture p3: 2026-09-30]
exports/renders/electronics_side.png

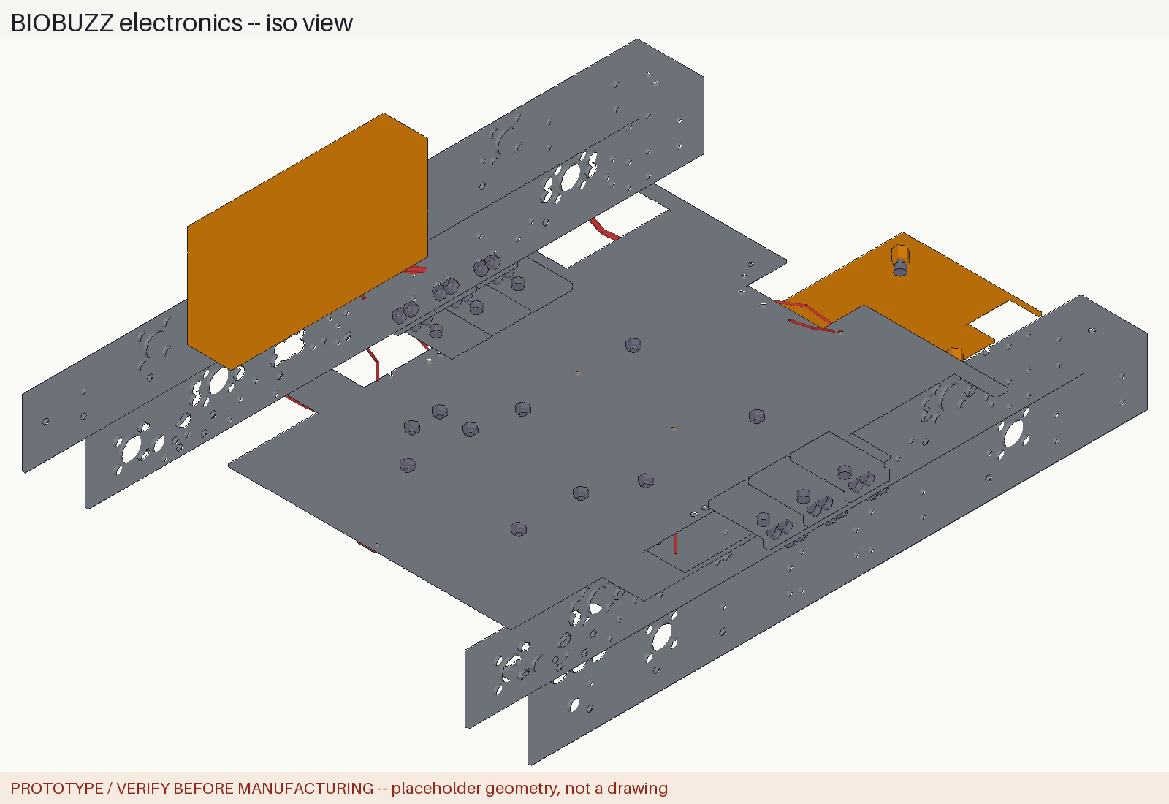
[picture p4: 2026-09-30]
exports/renders/electronics_iso.png

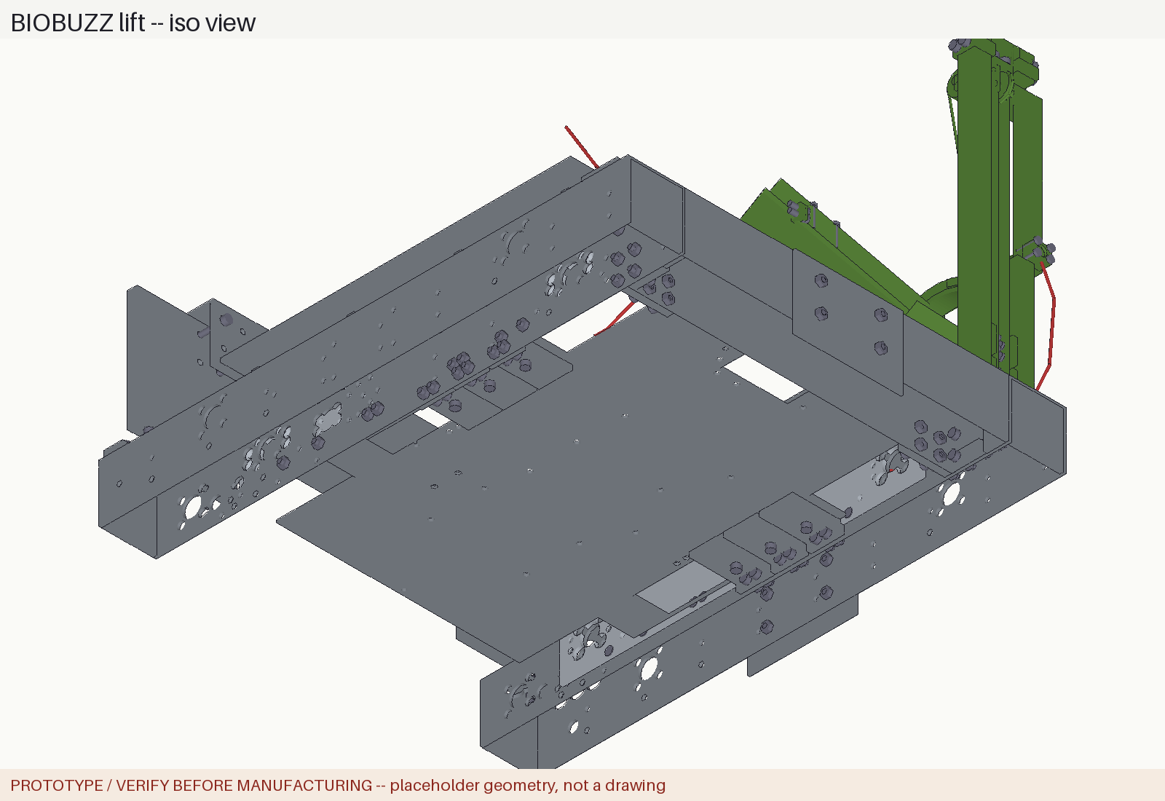
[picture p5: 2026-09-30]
exports/renders/lift_iso.png

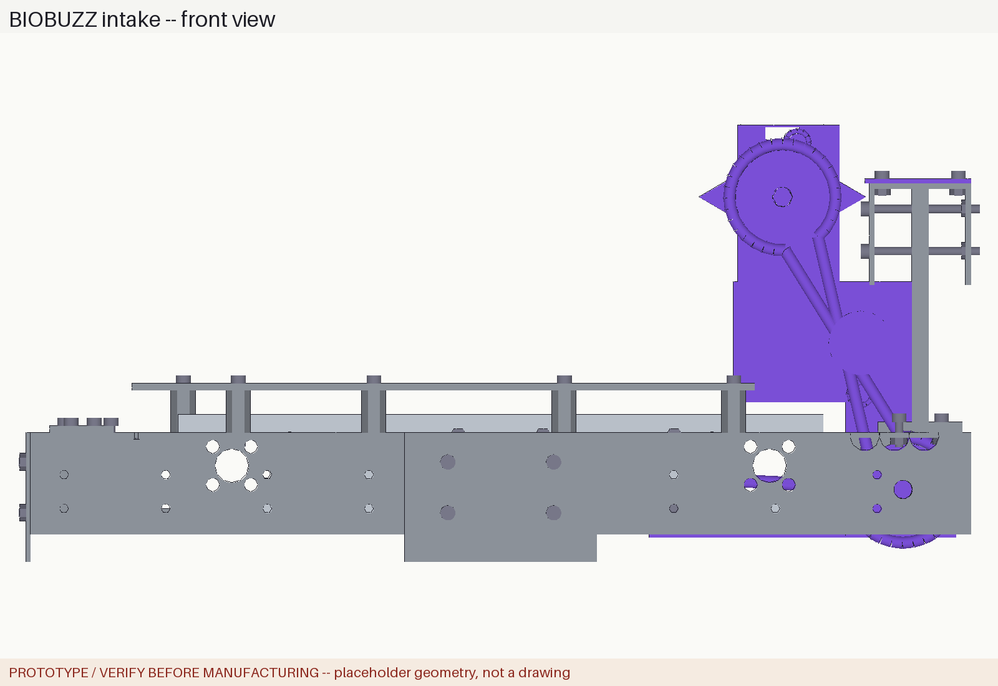
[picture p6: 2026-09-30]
exports/renders/intake_front.png

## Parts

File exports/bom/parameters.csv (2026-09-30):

alias | value | unit | status | source
start_cube | 457.2 | mm | VERIFIED | FIRST Tech Challenge match start volume 18in cube
chassis_sq | 444.5 | mm | UNVERIFIED | viewer frame 17.5in square; goBILDA 1120 kit nominal
rail_size | 48.0 | mm | VENDOR-PENDING | goBILDA 1120-series U-channel ~48mm outer section
rail_wall | 2.5 | mm | UNVERIFIED | assumed ~0.09in channel sheet wall; measure on hardware
rail_elev_z | 39.75 | mm | UNVERIFIED | viewer rail center 1.565in off ground
wheel_lat_off | 203.2 | mm | UNVERIFIED | viewer wheel track center 8.0in
wheel_out_gap | 43.18 | mm | UNVERIFIED | rail center to wheel center standoff (wheel_lat_off - rail_lat)
rail_lat_off | 160.02 | mm | UNVERIFIED | rail centerline offset; = wheel_lat_off - wheel_out_gap
wheel_lon_off | 127.0 | mm | UNVERIFIED | viewer wheel longitudinal station 5.0in
cross_x_off | 198.12 | mm | UNVERIFIED | viewer crossmember station 7.8in behind center
cross_half_len | 136.02 | mm | UNVERIFIED | viewer crossmember half-span 5.35in; butts rail inner faces
crown_z | 157.48 | mm | UNVERIFIED | viewer crown center height 6.2in
post_top_z | 178.98 | mm | UNVERIFIED | crown riser tongue top = crown web inner face
post_span | 84.13 | mm | UNVERIFIED | crown riser tongue span: mouth interior to web stand
wheel_dia | 96.0 | mm | VENDOR-PENDING | goBILDA 96mm mecanum set 3213-3606-0002, schematic 3606-0000-0096
wheel_width | 38.1 | mm | VENDOR-PENDING | viewer overall wheel width 1.5in
roller_count | 10.0 | count | VENDOR-PENDING | counted on goBILDA schematic 3606-0000-0096
mec_roll_dia | 14.0 | mm | VENDOR-PENDING | goBILDA schematic O14 roller
mec_roll_rad | 41.0 | mm | VENDOR-PENDING | roller-center radius; envelope radius = rad + len*sin45/2 + r*cos45 ~ wheel_dia/2
mec_roll_len | 24.0 | mm | UNVERIFIED | assumed roller length; stays inside O96x38 envelope
mec_roll_pitch | 36.0 | deg | VENDOR-PENDING | derived 360 / roller_count
mec_roll_phase | 18.0 | deg | UNVERIFIED | pitch phase: puts a roller dead-bottom (roller at 270 deg)
mec_roll_slant | 45.0 | deg | UNVERIFIED | mecanum roller slant
mec_pin_dia | 5.0 | mm | UNVERIFIED | roller axle pin dia; tips seat into face plates
mec_pin_len | 38.1 | mm | UNVERIFIED | roller pin overall; tips embed into face plates (declared)
wplate_dia | 92.0 | mm | UNVERIFIED | wheel side plate dia inside O96 envelope
wplate_thk | 4.0 | mm | UNVERIFIED | wheel side plate thickness
wplate_gap | 1.0 | mm | UNVERIFIED | wheel plate standoff inside the envelope face
hub_dia | 26.0 | mm | UNVERIFIED | wheel hub OD
hub_w | 30.1 | mm | UNVERIFIED | wheel hub width spanning the plate inner faces
hub_hex_af | 8.4 | mm | UNVERIFIED | hub hex bore across-flats; rides 8mm REX flats +0.4 clearance
plate_bore | 10.0 | mm | UNVERIFIED | wheel plate shaft clearance bore
rex_af | 8.0 | mm | VENDOR-PENDING | goBILDA 8mm REX shaft across-flats, series page
rex_crad | 4.62 | mm | VENDOR-PENDING | REX circumradius = af / (2 cos30); corners O9.24
shaft_len | 100.0 | mm | UNVERIFIED | live axle: socket seat -> outboard tip, viewver stack reconciled
shaft_tip_d | 7.4 | mm | UNVERIFIED | axle outboard tip turned+threaded M8x1.25 for retaining nut
shaft_tip_len | 9.2 | mm | UNVERIFIED | M8 tip: spans out plate bore + washer + nut + margin
sock_hex_af | 8.4 | mm | UNVERIFIED | motor output REX socket across-flats (hex bore)
sock_depth | 16.0 | mm | UNVERIFIED | socket bore depth into gearbox face
bear_w | 26.0 | mm | UNVERIFIED | bearing block face width
bear_h | 26.0 | mm | UNVERIFIED | bearing block face height
bear_t | 6.0 | mm | UNVERIFIED | bearing block thickness
bear_bore | 9.6 | mm | UNVERIFIED | bearing bore, clears REX circumcircle O9.24
bear_pilot_d | 15.6 | mm | UNVERIFIED | bearing pilot OD registers in O16 wall axle hole
bear_pilot_l | 2.0 | mm | UNVERIFIED | bearing pilot length
wall_axle_bore | 16.0 | mm | UNVERIFIED | rail wall axle clearance bore O16 (clears pilot O15.6)
bear_bolt_d | 4.4 | mm | UNVERIFIED | M4 clearance through bearing flange + wall
bear_bolt_off | 9.0 | mm | UNVERIFIED | bearing bolt square half-spacing
rivnut_d | 6.5 | mm | UNVERIFIED | M4 rivnut seat bore in rail wall; insert OD O6.4
collar_d | 18.0 | mm | UNVERIFIED | set-screw collar OD
collar_w | 5.0 | mm | UNVERIFIED | collar width
collar_bore | 9.6 | mm | UNVERIFIED | collar bore clears REX circumcircle O9.24
washer_d | 16.0 | mm | UNVERIFIED | M8 washer OD
washer_t | 1.8 | mm | UNVERIFIED | washer thickness
washer_bore | 9.6 | mm | UNVERIFIED | washer bore clears REX circumcircle
nut8_wrench | 13.0 | mm | UNVERIFIED | M8 nylock across-flats
nut8_h | 5.0 | mm | UNVERIFIED | retaining nut height
nut8_bore | 7.0 | mm | UNVERIFIED | nut thread core O7.0 on O7.4 tip = modeled thread interference
nut6_wrench | 10.0 | mm | UNVERIFIED | M6 nut across-flats
nut6_h | 5.0 | mm | UNVERIFIED | M6 nut height
nut6_bore | 5.0 | mm | UNVERIFIED | M6 nut core O5.0 on O6 pin = modeled thread interference
pinion_d | 17.0 | mm | UNVERIFIED | coupling hub OD riding axle in channel cavity
pinion_w | 7.0 | mm | UNVERIFIED | coupling hub width
pinion_bore | 9.6 | mm | UNVERIFIED | pinion slip bore clears REX circumcircle
motor_dia | 36.0 | mm | VENDOR-PENDING | goBILDA 5203-class ~36mm gearbox motor, series page
motor_gb_dia | 40.0 | mm | UNVERIFIED | planetary gearbox housing dia
motor_len | 65.0 | mm | UNVERIFIED | motor can length
motor_gb_l | 30.0 | mm | UNVERIFIED | gearbox housing length from mount face
mplate_len | 304.8 | mm | UNVERIFIED | motor plate spans both stations + grid margins
mplate_h | 48.3 | mm | UNVERIFIED | viewer motor plate 1.9in
mplate_t | 3.05 | mm | UNVERIFIED | viewer motor plate 0.12in
mplate_bore | 17.0 | mm | UNVERIFIED | shaft + bearing-pilot clearance bore through motor plate
motor_bolt_d | 4.0 | mm | UNVERIFIED | M4 motor face bolts (bolt_d), tap drill O3.3
motor_bolt_off | 16.0 | mm | UNVERIFIED | motor face bolt x offset (rect pattern clears bearings)
motor_bolt_dz | 4.0 | mm | UNVERIFIED | motor face bolt z offset
tap_drill | 3.3 | mm | UNVERIFIED | M4 tap drill dia
clamp_w | 12.0 | mm | UNVERIFIED | motor clamp width along Y
clamp_ear | 14.0 | mm | UNVERIFIED | clamp ear reach
bolt_d | 4.0 | mm | UNVERIFIED | M4 bolt shaft dia
bolt_head_d | 7.0 | mm | UNVERIFIED | M4 button head dia
bolt_head_h | 4.0 | mm | UNVERIFIED | M4 button head height
bolt_len | 16.0 | mm | UNVERIFIED | generic M4 bolt length
nut4_wrench | 7.0 | mm | UNVERIFIED | M4 nut across-flats
nut4_h | 3.2 | mm | UNVERIFIED | M4 nut height
nut4_bore | 3.6 | mm | UNVERIFIED | M4 nut core O3.6 on O4 shaft = modeled thread interference
pan_thk | 2.0 | mm | UNVERIFIED | belly pan sheet thickness
pan_w | 264.0 | mm | UNVERIFIED | viewer pan 10.6in wide
pan_len | 328.8 | mm | UNVERIFIED | pan spans electronics + pods; inside rail inner faces
pan_x_c | -9.4 | mm | UNVERIFIED | pan center offset
pan_z | 26.67 | mm | UNVERIFIED | viewer pan center 1.05in
pan_fillet | 8.0 | mm | UNVERIFIED | pan corner fillet
pan_brkt | 40.0 | mm | UNVERIFIED | pan bracket leg length
grid_hole_d | 4.4 | mm | VENDOR-PENDING | goBILDA M4 clearance grid hole O4.4
grid_pitch | 48.0 | mm | UNVERIFIED | grid hole row pitch used on walls/web (subset of 8mm grid)
deck_z | 85.3 | mm | UNVERIFIED | viewer electronics shelf level
deck_thk | 3.0 | mm | UNVERIFIED | deck panel thickness
deck_lane | 66.0 | mm | UNVERIFIED | hopper lane edge; decks span |Y| in [deck_in_off, rail outer]
deck_in_off | 66.0 | mm | UNVERIFIED | deck inner edge offset
deck_x_lo | -174.0 | mm | UNVERIFIED | deck rear extent
deck_x_hi | 120.0 | mm | UNVERIFIED | deck front extent
deck_post_d | 10.0 | mm | UNVERIFIED | deck standoff dia
shelf_z | 95.0 | mm | UNVERIFIED | electronics riser shelf center Z in the center lane
shelf_thk | 2.0 | mm | UNVERIFIED | shelf thickness
shelf_x_lo | -165.0 | mm | UNVERIFIED | shelf rear edge
shelf_x_hi | -30.0 | mm | UNVERIFIED | shelf front edge
shelf_y_lo | 65.0 | mm | UNVERIFIED | shelf edge: stays inside the deck flank gap
shelf_y_hi | 165.0 | mm | UNVERIFIED | shelf edge
standoff_d | 8.0 | mm | UNVERIFIED | shelf standoff dia
so_d | 8.0 | mm | UNVERIFIED | standoff dia (shelf risers)
odo_pod_lat | 116.84 | mm | UNVERIFIED | viewer pod 4.6in
odo_pod_x | 30.48 | mm | UNVERIFIED | lateral pods station
odo_pod_lon_x | -160.0 | mm | UNVERIFIED | rear pod station
odo_wheel_d | 48.0 | mm | VENDOR-PENDING | 48mm omni tracking wheel, vendor typical
odo_wheel_w | 16.0 | mm | UNVERIFIED | odo wheel width
odo_arm_len | 30.0 | mm | UNVERIFIED | odo arm drop
odo_block_h | 12.0 | mm | UNVERIFIED | pod mount block height
odo_pin_d | 6.0 | mm | UNVERIFIED | odo wheel/pivot pin dia
odo_spring_d | 8.0 | mm | UNVERIFIED | pod preload spring OD
batt_l | 95.0 | mm | VENDOR-PENDING | REV 3000mAh pack envelope approx
batt_w | 65.0 | mm | UNVERIFIED | battery width
batt_h | 40.0 | mm | UNVERIFIED | battery height; strap top stays under the deck
batt_x | 65.0 | mm | UNVERIFIED | battery station; pack fully on the pan, clear of hubs
batt_y | 0.0 | mm | UNVERIFIED | battery offset; strap feet stay clear of the clamp notches
strap_w | 30.0 | mm | UNVERIFIED | battery strap width
strap_t | 1.5 | mm | UNVERIFIED | strap band thickness
strap_foot | 12.0 | mm | UNVERIFIED | strap foot tab reach
hub_l | 142.0 | mm | VENDOR-PENDING | REV hub 5.6in long
ehub_w | 74.0 | mm | VENDOR-PENDING | REV hub 2.9in wide
hub_h | 29.0 | mm | UNVERIFIED | REV hub 1.15in tall
ctrl_x | -29.0 | mm | UNVERIFIED | viewer ctrl hub station
ctrl_y | 11.0 | mm | UNVERIFIED | viewer ctrl hub offset
exp_x | 0.0 | mm | UNVERIFIED | exp hub center on R rail out-face
exp_y | -201.52 | mm | UNVERIFIED | exp hub block center; mount face at R rail out-wall
ehub_z | 3.0 | mm | UNVERIFIED | exp hub base elevation on R rail out-face
sw_x | 52.5 | mm | UNVERIFIED | main switch station
sw_y | -57.0 | mm | UNVERIFIED | main switch offset
sw_l | 15.0 | mm | UNVERIFIED | switch body length
sw_h | 13.0 | mm | UNVERIFIED | switch body height
sw_w | 9.0 | mm | UNVERIFIED | switch body width
wire_d | 3.0 | mm | UNVERIFIED | wire bundle dia
plate_num_w | 91.0 | mm | UNVERIFIED | number plate width
plate_num_h | 61.0 | mm | UNVERIFIED | number plate height
plate_num_t | 2.0 | mm | UNVERIFIED | number plate thickness
endcap_t | 3.0 | mm | UNVERIFIED | channel end cap face
gusset_leg | 35.0 | mm | UNVERIFIED | corner gusset leg
gusset_t | 6.0 | mm | UNVERIFIED | corner gusset thickness
intake_x | 190.0 | mm | UNVERIFIED | traction roller center station (viewer 7.15in fwd)
roller_low_z | 36.8 | mm | UNVERIFIED | traction roller axis height (viewer 1.45in)
roller_low_r | 25.4 | mm | UNVERIFIED | traction roller radius (viewer 2in dia ribbed rubber)
roller_len | 255.0 | mm | UNVERIFIED | roller working span between cheeks (viewer 10.2in)
roller_top_x | 133.0 | mm | UNVERIFIED | star roller station -- CAD corrected: viewer Z put the nip at -10.15mm surface gap, physically impossible; D13
roller_top_z | 175.0 | mm | UNVERIFIED | star roller axis -- CAD corrected for >=73.2mm rest nip gap; D13
roller_top_r | 39.35 | mm | UNVERIFIED | star roller tip radius (viewer 3.1in dia star roller)
star_core_r | 22.0 | mm | UNVERIFIED | star roller rigid carrier radius under the compliant tips
float_travel | 17.8 | mm | UNVERIFIED | floating top-roller vertical give (viewer 0.7in)
cheek_lat_off | 130.5 | mm | UNVERIFIED | intake cheek plate center -- CAD corrected inboard, flush on the rail inner wall face (viewer 5.45in interpenetrated it); D13
cheek_thk | 5.0 | mm | UNVERIFIED | PETG cheek plate thickness
sprocket_plane | 164.0 | mm | UNVERIFIED | #25 sprocket/chain plane inside the right rail channel
belt_plane | 155.0 | mm | UNVERIFIED | crossed-belt plane in the left rail channel, outboard of the in-wall cavity bearing
int_motor_x | 76.0 | mm | UNVERIFIED | intake motor station under the hopper incline
int_motor_z | 43.0 | mm | UNVERIFIED | intake motor axis height
int_motor_lat | 101.6 | mm | UNVERIFIED | intake motor can center offset (viewer 4.0in)
sprocket9_pd | 18.6 | mm | VENDOR-PENDING | #25 chain 9T sprocket pitch dia
sprocket16_pd | 32.6 | mm | VENDOR-PENDING | #25 chain 16T sprocket pitch dia
belt_pul_d | 40.0 | mm | UNVERIFIED | HTD crossed-belt pulley pitch dia
spring_post_d | 8.0 | mm | UNVERIFIED | torsion-spring post dia on the cheek tower
spring_coil_d | 16.0 | mm | UNVERIFIED | torsion spring coil OD (music wire, viewer-scaled)
lane_wid | 114.0 | mm | UNVERIFIED | hopper lane inner width (walls at +-54.6); >= 93 for NECTAR
hop_wall_y | 60.0 | mm | UNVERIFIED | hopper side wall plane offset (viewer 2.15in)
hopper_incline | 20.0 | deg | UNVERIFIED | hopper floor incline angle (viewer 20deg)
hop_floor_cx | 62.0 | mm | UNVERIFIED | incline floor center station (viewer -2.45in z)
hop_floor_len | 107.0 | mm | UNVERIFIED | incline floor length along slope (viewer 4.2in)
hop_floor_w | 107.0 | mm | UNVERIFIED | incline floor width, fits inside the lane
hop_wall_x0 | -73.0 | mm | UNVERIFIED | hopper wall rear edge
hop_wall_x1 | 92.0 | mm | UNVERIFIED | hopper wall front edge -- stops clear of the star roller (X>=93.6)
hop_wall_z0 | 70.0 | mm | UNVERIFIED | wall bottom edge, below the incline surface everywhere
hop_wall_z1 | 180.0 | mm | UNVERIFIED | wall top edge
hop_curb_x | -70.0 | mm | UNVERIFIED | rear curb station sealing under the column mouth
feed_x | -36.8 | mm | UNVERIFIED | feed wheel axis station (viewer 1.45in)
feed_z | 130.8 | mm | UNVERIFIED | feed wheel axis height (viewer 5.15in)
feed_wheel_r | 40.65 | mm | VENDOR-PENDING | green compliant feed wheel radius (viewer 3.2in dia)
feed_wheel_w | 40.0 | mm | UNVERIFIED | feed wheel width
feed_motor_z | 71.1 | mm | UNVERIFIED | feed motor axis height (viewer 2.8in)
feed_motor_lat | 104.0 | mm | UNVERIFIED | feed motor can center offset
feed_gear_d | 59.8 | mm | UNVERIFIED | feed drop-pair gear pitch dia; meshes at the 59.7mm shaft spacing
column_x | -66.0 | mm | UNVERIFIED | feed column axis station == AXIS_TURRET (viewer 2.6in)
column_id | 104.0 | mm | UNVERIFIED | feed column bore; contract gate >=103 (4in nominal +margin)
column_od | 110.0 | mm | UNVERIFIED | feed column OD, 3mm polycarb wall
column_z0 | 88.0 | mm | UNVERIFIED | column lower end
column_z1 | 254.0 | mm | UNVERIFIED | column top, above the sprint-03 deck interface
col_flange_z | 90.0 | mm | UNVERIFIED | column base flange plate Z
col_post_off | 55.0 | mm | UNVERIFIED | column support post x offset from axis
col_post_lat | 76.0 | mm | UNVERIFIED | column support post y offset from axis (all four on the west lobe, clear of the hopper walls)
gate_y | 73.7 | mm | UNVERIFIED | gate servo offset magnitude on the right wall (viewer 2.9in; moved off the +Y port corridor)
gate_z | 174.0 | mm | UNVERIFIED | gate servo height / flag sweep station
div_z | 204.0 | mm | UNVERIFIED | diverter port center height on the +Y column wall
div_port_d | 100.0 | mm | UNVERIFIED | side-port flange bore dia, >=93 + sphere margin for NECTAR
agit_x | 66.0 | mm | UNVERIFIED | agitator servo station (viewer -2.6in)
agit_y | -73.7 | mm | UNVERIFIED | agitator servo offset on the right wall
agit_z | 115.6 | mm | UNVERIFIED | agitator servo height
snsr_x | 96.0 | mm | UNVERIFIED | entry color sensor station
snsr_y | -58.0 | mm | UNVERIFIED | sensor offset at hopper entry
snsr_z | 86.0 | mm | UNVERIFIED | sensor height at hopper entry
ball_p_dia | 71.0 | mm | VERIFIED | POLLEN element dia, Competition Manual sec.9.8
ball_n_dia | 91.0 | mm | VERIFIED | NECTAR element dia, Competition Manual sec.9.8
ball_clear | 2.0 | mm | UNVERIFIED | ball-path radial clearance margin
tower_lat_off | 130.8 | mm | UNVERIFIED | tower riser plate center offset (viewer 5.15in)
tower_thk | 3.0 | mm | UNVERIFIED | polycarb tower riser sheet
tower_x0 | -176.0 | mm | UNVERIFIED | tower riser rear edge (deck panel edge x-174 + margin)
tower_x1 | 0.0 | mm | UNVERIFIED | tower riser front edge
tower_span | 157.2 | mm | UNVERIFIED | tower riser column span (frame deck top to turret deck underside)
turret_deck_z0 | 244.0 | mm | UNVERIFIED | turret deck plate bottom -- REF_DECK_IFACE + 1
turret_deck_t | 4.0 | mm | UNVERIFIED | PETG turret deck sheet
deck_bore_d | 114.0 | mm | UNVERIFIED | deck/plate center bore, clears column_od 110 +4 (D3-B)
yaw_off | 72.8 | mm | UNVERIFIED | yaw pinion center distance -- (ring_pd + pinion_pd)/2 external mesh (FC1/D3-A); clears column OD55 -> pinion r60.8..84.8
susan_d | 132.0 | mm | VENDOR-PENDING | lazy-susan race OD 5.2in nominal
susan_bore_d | 116.0 | mm | UNVERIFIED | lazy-susan center opening -- clears column_od 110 with margin (race band r58..66)
susan_race_h | 4.25 | mm | UNVERIFIED | one race height; pair stacks 8.5 total (FC2 stack z248-256.5)
ring_pd | 121.9 | mm | VENDOR-PENDING | 72T ring gear pitch dia, teeth on the OUTER rim (D3-A)
ring_od | 128.8 | mm | UNVERIFIED | ring gear outer tip dia ~ ring_pd + 2*addendum
pinion_pd | 23.7 | mm | VENDOR-PENDING | 14T brass yaw pinion pitch dia
pinion_od | 27.8 | mm | UNVERIFIED | pinion tip dia
yaw_shaft_d | 8.0 | mm | UNVERIFIED | yaw pinion REX shaft
plate_od | 170.0 | mm | UNVERIFIED | rotating turret plate dia (viewer 6.7in)
plate_t | 4.0 | mm | UNVERIFIED | acetal turret plate
cheek_lat | 66.5 | mm | UNVERIFIED | launcher cheek plate offset (viewer 2.62in)
fly_axis_x | -80.0 | mm | UNVERIFIED | flywheel axis station (viewer -3.15in rel axis)
fly_axis_z | 308.5 | mm | UNVERIFIED | flywheel axis height -- raised 292->308.5: wheel r44.45 at 292 dipped to z247.5 and interpenetrated the column top (z254), the susan races and the ring gear; at 308.5 the wheel bottom 264.05 clears the static stack and grazes only the plate-top band (relieved by the plate scallops)
fly_d | 88.9 | mm | VENDOR-PENDING | flywheel OD 3.5in compliant (alu hub + urethane band)
fly_w | 18.3 | mm | UNVERIFIED | flywheel face width
fly_motor_d | 36.0 | mm | VENDOR-PENDING | 5203-class motor can dia
nip_gap | 73.7 | mm | UNVERIFIED | flywheel face-to-face gap -> ~19% NECTAR compression
hood_piv_x | -100.3 | mm | UNVERIFIED | hood pivot station
hood_piv_z | 359.0 | mm | UNVERIFIED | hood pivot axis height -- D3-E+: the viewer's z321 pivot sat INSIDE the wheel disc (r35.4 vs O44.5) and the axle would pierce both wheels; 346 cleared the z292 wheel top (336.4) but with fly_axis_z 308.5 the wheel top is 352.95 -> pivot 359 keeps the O8 pin 2mm clear of the rim
hood_piv_d | 8.0 | mm | UNVERIFIED | hood pivot axle dia
cam_x | -8.0 | mm | UNVERIFIED | vision camera station on the plate (on-plate bracket keeps the yaw sweep inside the plate+motor envelope)
cam_z | 286.0 | mm | UNVERIFIED | camera body height
magnet_r | 78.7 | mm | UNVERIFIED | yaw index magnet radius on the plate rim (viewer 3.1in)
lift_x | -185.4 | mm | UNVERIFIED | mast center station on the left rail (viewer 7.3in)
lift_y0 | 144.0 | mm | UNVERIFIED | inner guide rail offset -- D3-C corrected onto the rail top flange (viewer y198 lands off the 136..184 flange)
lift_y1 | 180.0 | mm | UNVERIFIED | outer guide rail offset
lift_z0 | 63.8 | mm | UNVERIFIED | mast base z = rail top flange face
lift_rail_len | 269.0 | mm | UNVERIFIED | fixed slide-rail length (viewer 10.6in) -- z64..333
slide_sec | 14.0 | mm | UNVERIFIED | slide extrusion section
s1_len | 239.0 | mm | UNVERIFIED | stage-1 slide bar length (viewer 9.4in)
s2_len | 218.0 | mm | UNVERIFIED | stage-2 slide bar length (viewer 8.6in)
mast_top_z | 330.0 | mm | UNVERIFIED | mast top tie z
cradle_x | -127.0 | mm | UNVERIFIED | cradle pivot station (viewer 5.0in fwd of mast)
cradle_y | 178.0 | mm | UNVERIFIED | cradle pivot offset
cradle_z | 140.0 | mm | UNVERIFIED | cradle bowl park height -- FC3: the chute needs the drop
cradle_id | 99.0 | mm | UNVERIFIED | cradle cup bore -- D91 + 2x3 foam + clearance (FC4)
deploy_z | 566.0 | mm | UNVERIFIED | deployed cradle rim height inside R105 736.5
rope_d | 1.5 | mm | UNVERIFIED | dyneema lift line
winch_z | 18.0 | mm | UNVERIFIED | winch block height (low-profile for S17)
chute_w | 97.0 | mm | UNVERIFIED | load-chute tray inner width -- D93 + margin (FC4)
rail_len | 444.5000 | mm | UNVERIFIED | alias: rail length
axle_len | 100.0000 | mm | UNVERIFIED | alias: live axle length
rex_bore | 9.6000 | mm | VENDOR-PENDING | alias: 9.6mm REX clearance bore
brg_in_off | 138.5200 | mm | UNVERIFIED | alias: inner bearing face offset
brg_out_off | 181.5200 | mm | UNVERIFIED | alias: outer bearing face offset
motor_lat_off | 70.4700 | mm | UNVERIFIED | alias: motor can center offset
mount_plate_off | 134.4950 | mm | UNVERIFIED | alias: mount plate center offset
collar_off | 148.8200 | mm | UNVERIFIED | alias: shaft collar center offset
washer_off | 145.4200 | mm | UNVERIFIED | alias: shaft washer center offset
pinion_off | 155.8200 | mm | UNVERIFIED | alias: pinion/coupler center offset
nut_off | 225.5500 | mm | UNVERIFIED | alias: nylock center offset
clamp1_off | 126.9700 | mm | UNVERIFIED | alias: inner clamp center offset
clamp2_off | 96.9700 | mm | UNVERIFIED | alias: outer clamp center offset
nip_rest_gap | 84.7433 | mm | UNVERIFIED | alias: surface gap along the roller nip line
tower_z1 | 244.0000 | mm | UNVERIFIED | alias: tower top = turret deck underside
plate_z | 265.0000 | mm | UNVERIFIED | alias: plate center z = susan top 256.5 + ring 6.5 + plate/2
stop_z | 326.0000 | mm | UNVERIFIED | alias: hard-stop collar z = rail top - 9.75

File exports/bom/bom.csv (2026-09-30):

subsystem | description | material | spec | status | qty | objects
drivetrain | 5203-class gearbox motor | motor | O36 can / O40 gb | VENDOR-PENDING | 4 | MOTOR_FL MOTOR_FR MOTOR_RL MOTOR_RR
drivetrain | 8mm REX live axle, M8 tip | steel | L=112 | VENDOR-PENDING | 4 | AXLE_FL AXLE_FR AXLE_RL AXLE_RR
drivetrain | BOLT_HUB_FL | steel | - | UNVERIFIED | 1 | BOLT_HUB_FL
drivetrain | BOLT_HUB_FR | steel | - | UNVERIFIED | 1 | BOLT_HUB_FR
drivetrain | BOLT_HUB_RL | steel | - | UNVERIFIED | 1 | BOLT_HUB_RL
drivetrain | BOLT_HUB_RR | steel | - | UNVERIFIED | 1 | BOLT_HUB_RR
drivetrain | M8 thin nylock axle nut | steel | M8 nylock h5 | UNVERIFIED | 4 | NUT_AXLE_FL NUT_AXLE_FR NUT_AXLE_RL NUT_AXLE_RR
drivetrain | ROLLER_FL_00_B | steel | - | VENDOR-PENDING | 1 | ROLLER_FL_00_B
drivetrain | ROLLER_FL_01_B | steel | - | VENDOR-PENDING | 1 | ROLLER_FL_01_B
drivetrain | ROLLER_FL_02_B | steel | - | VENDOR-PENDING | 1 | ROLLER_FL_02_B
drivetrain | ROLLER_FL_03_B | steel | - | VENDOR-PENDING | 1 | ROLLER_FL_03_B
drivetrain | ROLLER_FL_04_B | steel | - | VENDOR-PENDING | 1 | ROLLER_FL_04_B
drivetrain | ROLLER_FL_05_B | steel | - | VENDOR-PENDING | 1 | ROLLER_FL_05_B
drivetrain | ROLLER_FL_06_B | steel | - | VENDOR-PENDING | 1 | ROLLER_FL_06_B
drivetrain | ROLLER_FL_07_B | steel | - | VENDOR-PENDING | 1 | ROLLER_FL_07_B
drivetrain | ROLLER_FL_08_B | steel | - | VENDOR-PENDING | 1 | ROLLER_FL_08_B
drivetrain | ROLLER_FL_09_B | steel | - | VENDOR-PENDING | 1 | ROLLER_FL_09_B
drivetrain | ROLLER_FR_00_B | steel | - | VENDOR-PENDING | 1 | ROLLER_FR_00_B
drivetrain | ROLLER_FR_01_B | steel | - | VENDOR-PENDING | 1 | ROLLER_FR_01_B
drivetrain | ROLLER_FR_02_B | steel | - | VENDOR-PENDING | 1 | ROLLER_FR_02_B
drivetrain | ROLLER_FR_03_B | steel | - | VENDOR-PENDING | 1 | ROLLER_FR_03_B
drivetrain | ROLLER_FR_04_B | steel | - | VENDOR-PENDING | 1 | ROLLER_FR_04_B
drivetrain | ROLLER_FR_05_B | steel | - | VENDOR-PENDING | 1 | ROLLER_FR_05_B
drivetrain | ROLLER_FR_06_B | steel | - | VENDOR-PENDING | 1 | ROLLER_FR_06_B
drivetrain | ROLLER_FR_07_B | steel | - | VENDOR-PENDING | 1 | ROLLER_FR_07_B
drivetrain | ROLLER_FR_08_B | steel | - | VENDOR-PENDING | 1 | ROLLER_FR_08_B
drivetrain | ROLLER_FR_09_B | steel | - | VENDOR-PENDING | 1 | ROLLER_FR_09_B
drivetrain | ROLLER_RL_00_B | steel | - | VENDOR-PENDING | 1 | ROLLER_RL_00_B
drivetrain | ROLLER_RL_01_B | steel | - | VENDOR-PENDING | 1 | ROLLER_RL_01_B
drivetrain | ROLLER_RL_02_B | steel | - | VENDOR-PENDING | 1 | ROLLER_RL_02_B
drivetrain | ROLLER_RL_03_B | steel | - | VENDOR-PENDING | 1 | ROLLER_RL_03_B
drivetrain | ROLLER_RL_04_B | steel | - | VENDOR-PENDING | 1 | ROLLER_RL_04_B
drivetrain | ROLLER_RL_05_B | steel | - | VENDOR-PENDING | 1 | ROLLER_RL_05_B
drivetrain | ROLLER_RL_06_B | steel | - | VENDOR-PENDING | 1 | ROLLER_RL_06_B
drivetrain | ROLLER_RL_07_B | steel | - | VENDOR-PENDING | 1 | ROLLER_RL_07_B
drivetrain | ROLLER_RL_08_B | steel | - | VENDOR-PENDING | 1 | ROLLER_RL_08_B
drivetrain | ROLLER_RL_09_B | steel | - | VENDOR-PENDING | 1 | ROLLER_RL_09_B
drivetrain | ROLLER_RR_00_B | steel | - | VENDOR-PENDING | 1 | ROLLER_RR_00_B
drivetrain | ROLLER_RR_01_B | steel | - | VENDOR-PENDING | 1 | ROLLER_RR_01_B
drivetrain | ROLLER_RR_02_B | steel | - | VENDOR-PENDING | 1 | ROLLER_RR_02_B
drivetrain | ROLLER_RR_03_B | steel | - | VENDOR-PENDING | 1 | ROLLER_RR_03_B
drivetrain | ROLLER_RR_04_B | steel | - | VENDOR-PENDING | 1 | ROLLER_RR_04_B
drivetrain | ROLLER_RR_05_B | steel | - | VENDOR-PENDING | 1 | ROLLER_RR_05_B
drivetrain | ROLLER_RR_06_B | steel | - | VENDOR-PENDING | 1 | ROLLER_RR_06_B
drivetrain | ROLLER_RR_07_B | steel | - | VENDOR-PENDING | 1 | ROLLER_RR_07_B
drivetrain | ROLLER_RR_08_B | steel | - | VENDOR-PENDING | 1 | ROLLER_RR_08_B
drivetrain | ROLLER_RR_09_B | steel | - | VENDOR-PENDING | 1 | ROLLER_RR_09_B
drivetrain | WHEEL_ASSY_FL | steel | - | VENDOR-PENDING | 1 | WHEEL_ASSY_FL
drivetrain | WHEEL_ASSY_FR | steel | - | VENDOR-PENDING | 1 | WHEEL_ASSY_FR
drivetrain | WHEEL_ASSY_RL | steel | - | VENDOR-PENDING | 1 | WHEEL_ASSY_RL
drivetrain | WHEEL_ASSY_RR | steel | - | VENDOR-PENDING | 1 | WHEEL_ASSY_RR
drivetrain | WHEEL_HUB_FL | steel | - | VENDOR-PENDING | 1 | WHEEL_HUB_FL
drivetrain | WHEEL_HUB_FR | steel | - | VENDOR-PENDING | 1 | WHEEL_HUB_FR
drivetrain | WHEEL_HUB_RL | steel | - | VENDOR-PENDING | 1 | WHEEL_HUB_RL
drivetrain | WHEEL_HUB_RR | steel | - | VENDOR-PENDING | 1 | WHEEL_HUB_RR
drivetrain | WHEEL_PLATE_FL_IN | steel | - | VENDOR-PENDING | 1 | WHEEL_PLATE_FL_IN
drivetrain | WHEEL_PLATE_FL_OUT | steel | - | VENDOR-PENDING | 1 | WHEEL_PLATE_FL_OUT
drivetrain | WHEEL_PLATE_FR_IN | steel | - | VENDOR-PENDING | 1 | WHEEL_PLATE_FR_IN
drivetrain | WHEEL_PLATE_FR_OUT | steel | - | VENDOR-PENDING | 1 | WHEEL_PLATE_FR_OUT
drivetrain | WHEEL_PLATE_RL_IN | steel | - | VENDOR-PENDING | 1 | WHEEL_PLATE_RL_IN
drivetrain | WHEEL_PLATE_RL_OUT | steel | - | VENDOR-PENDING | 1 | WHEEL_PLATE_RL_OUT
drivetrain | WHEEL_PLATE_RR_IN | steel | - | VENDOR-PENDING | 1 | WHEEL_PLATE_RR_IN
drivetrain | WHEEL_PLATE_RR_OUT | steel | - | VENDOR-PENDING | 1 | WHEEL_PLATE_RR_OUT
drivetrain | flange bearing block | aluminum | 26x26x6 O9.6 bore O15.6 pilot | VENDOR-PENDING | 8 | BRG_IN_FL BRG_OUT_FL BRG_IN_FR BRG_OUT_FR BRG_IN_RL BRG_OUT_RL BRG_IN_RR BRG_OUT_RR
drivetrain | motor clamp block | aluminum | O40.5 bore + ears | UNVERIFIED | 8 | CLAMP_FL_2 CLAMP_FL_1 CLAMP_FR_2 CLAMP_FR_1 CLAMP_RL_2 CLAMP_RL_1 CLAMP_RR_2 CLAMP_RR_1
drivetrain | motor mount plate | aluminum | 348.5x48.3x3.05 | UNVERIFIED | 2 | MOUNT_PLATE_L MOUNT_PLATE_R
drivetrain | shaft washer/collar/pinion | steel | O16/18/17 | UNVERIFIED | 12 | WSH_AXLE_FL COLLAR_FL PINION_FL WSH_AXLE_FR COLLAR_FR PINION_FR WSH_AXLE_RL COLLAR_RL PINION_RL WSH_AXLE_RR COLLAR_RR PINION_RR
electronics | 3000mAh 12V battery | battery | 75x45x22 | VENDOR-PENDING | 1 | BATTERY
electronics | REV hub (ctrl) | hub | 142x79x29 | VENDOR-PENDING | 1 | HUB_CTRL
electronics | REV hub (exp) | hub | 142x79x29 | VENDOR-PENDING | 1 | HUB_EXP
electronics | SCRW_AGSV x4 | steel | - | UNVERIFIED | 4 | SCRW_AGSV_0 SCRW_AGSV_1 SCRW_AGSV_2 SCRW_AGSV_3
electronics | SCRW_CAM x2 | steel | - | UNVERIFIED | 2 | SCRW_CAM_0 SCRW_CAM_1
electronics | SCRW_CARM x2 | steel | - | UNVERIFIED | 2 | SCRW_CARM_0 SCRW_CARM_1
electronics | SCRW_CHL x8 | steel | - | UNVERIFIED | 8 | SCRW_CHL_0_0 SCRW_CHL_0_1 SCRW_CHL_1_0 SCRW_CHL_2_0 SCRW_CHL_2_1 SCRW_CHL_3_0 SCRW_CHL_3_1 SCRW_CHL_3_2
electronics | SCRW_DVSV x4 | steel | - | UNVERIFIED | 4 | SCRW_DVSV_0 SCRW_DVSV_1 SCRW_DVSV_2 SCRW_DVSV_3
electronics | SCRW_ENC_LAT_L x2 | steel | - | UNVERIFIED | 2 | SCRW_ENC_LAT_L_0 SCRW_ENC_LAT_L_1
electronics | SCRW_ENC_LAT_R x2 | steel | - | UNVERIFIED | 2 | SCRW_ENC_LAT_R_0 SCRW_ENC_LAT_R_1
electronics | SCRW_ENC_LON x2 | steel | - | UNVERIFIED | 2 | SCRW_ENC_LON_0 SCRW_ENC_LON_1
electronics | SCRW_GSV x4 | steel | - | UNVERIFIED | 4 | SCRW_GSV_0 SCRW_GSV_1 SCRW_GSV_2 SCRW_GSV_3
electronics | SCRW_HCOL_L | steel | - | UNVERIFIED | 1 | SCRW_HCOL_L
electronics | SCRW_HCOL_R | steel | - | UNVERIFIED | 1 | SCRW_HCOL_R
electronics | SCRW_HSV x4 | steel | - | UNVERIFIED | 4 | SCRW_HSV_0 SCRW_HSV_1 SCRW_HSV_2 SCRW_HSV_3
electronics | SCRW_S1T_L0 x2 | steel | - | UNVERIFIED | 2 | SCRW_S1T_L0_0 SCRW_S1T_L0_1
electronics | SCRW_S1T_L1 x2 | steel | - | UNVERIFIED | 2 | SCRW_S1T_L1_0 SCRW_S1T_L1_1
electronics | SCRW_S1T_R0 x2 | steel | - | UNVERIFIED | 2 | SCRW_S1T_R0_0 SCRW_S1T_R0_1
electronics | SCRW_S1T_R1 x2 | steel | - | UNVERIFIED | 2 | SCRW_S1T_R1_0 SCRW_S1T_R1_1
electronics | SCRW_S2T x4 | steel | - | UNVERIFIED | 4 | SCRW_S2T_0_0 SCRW_S2T_0_1 SCRW_S2T_1_0 SCRW_S2T_1_1
electronics | SCRW_SNSR x2 | steel | - | UNVERIFIED | 2 | SCRW_SNSR_0 SCRW_SNSR_1
electronics | SCRW_SW x2 | steel | - | UNVERIFIED | 2 | SCRW_SW_0 SCRW_SW_1
electronics | SCRW_TSV x4 | steel | - | UNVERIFIED | 4 | SCRW_TSV_0 SCRW_TSV_1 SCRW_TSV_2 SCRW_TSV_3
electronics | SCRW_YSV x4 | steel | - | UNVERIFIED | 4 | SCRW_YSV_0 SCRW_YSV_1 SCRW_YSV_2 SCRW_YSV_3
electronics | adhesive cable clip | nylon | 12x12x4 | UNVERIFIED | 4 | CLIP_0 CLIP_1 CLIP_2 CLIP_3
electronics | battery strap | nylon | wrap | UNVERIFIED | 2 | BATT_STRAP_0 BATT_STRAP_1
electronics | electronics shelf | polycarb | 86x128x2 | UNVERIFIED | 1 | ELEC_SHELF
electronics | main power switch | switch | 15x9x13 | UNVERIFIED | 1 | MAIN_SWITCH
electronics | shelf standoff | aluminum | O8x31 | UNVERIFIED | 4 | STANDOFF_0 STANDOFF_1 STANDOFF_2 STANDOFF_3
electronics | switch bracket | aluminum | L30x20x24 | UNVERIFIED | 1 | SWITCH_BRKT
electronics | wire run | wire | O1.5 | UNVERIFIED | 3 | WIRE_ENC_LAT_L WIRE_ENC_LAT_R WIRE_ENC_LON
electronics | wire run | wire | O2 | UNVERIFIED | 4 | WIRE_HOOD_SV WIRE_WINCH WIRE_TILT_SV WIRE_YAW_SV
electronics | wire run | wire | O2.5 | UNVERIFIED | 2 | WIRE_FLY_L WIRE_FLY_R
electronics | wire run | wire | O3 | UNVERIFIED | 6 | WIRE_HUB_RS485 WIRE_MTR_FL WIRE_MTR_RL WIRE_MTR_FR WIRE_MTR_RR WIRE_CAM_USB
electronics | wire run | wire | O4 | UNVERIFIED | 2 | WIRE_BATT_SW WIRE_SW_CTRL
fasteners | BOLT_AGBRK x4 | steel | - | UNVERIFIED | 4 | BOLT_AGBRK_0 BOLT_AGBRK_1 BOLT_AGBRK_2 BOLT_AGBRK_3
fasteners | BOLT_BRG_IN_FL x4 | steel | - | UNVERIFIED | 4 | BOLT_BRG_IN_FL_00 BOLT_BRG_IN_FL_01 BOLT_BRG_IN_FL_10 BOLT_BRG_IN_FL_11
fasteners | BOLT_BRG_IN_FR x4 | steel | - | UNVERIFIED | 4 | BOLT_BRG_IN_FR_00 BOLT_BRG_IN_FR_01 BOLT_BRG_IN_FR_10 BOLT_BRG_IN_FR_11
fasteners | BOLT_BRG_IN_RL x4 | steel | - | UNVERIFIED | 4 | BOLT_BRG_IN_RL_00 BOLT_BRG_IN_RL_01 BOLT_BRG_IN_RL_10 BOLT_BRG_IN_RL_11
fasteners | BOLT_BRG_IN_RR x4 | steel | - | UNVERIFIED | 4 | BOLT_BRG_IN_RR_00 BOLT_BRG_IN_RR_01 BOLT_BRG_IN_RR_10 BOLT_BRG_IN_RR_11
fasteners | BOLT_BRG_OUT_FL x4 | steel | - | UNVERIFIED | 4 | BOLT_BRG_OUT_FL_00 BOLT_BRG_OUT_FL_01 BOLT_BRG_OUT_FL_10 BOLT_BRG_OUT_FL_11
fasteners | BOLT_BRG_OUT_FR x4 | steel | - | UNVERIFIED | 4 | BOLT_BRG_OUT_FR_00 BOLT_BRG_OUT_FR_01 BOLT_BRG_OUT_FR_10 BOLT_BRG_OUT_FR_11
fasteners | BOLT_BRG_OUT_RL x4 | steel | - | UNVERIFIED | 4 | BOLT_BRG_OUT_RL_00 BOLT_BRG_OUT_RL_01 BOLT_BRG_OUT_RL_10 BOLT_BRG_OUT_RL_11
fasteners | BOLT_BRG_OUT_RR x4 | steel | - | UNVERIFIED | 4 | BOLT_BRG_OUT_RR_00 BOLT_BRG_OUT_RR_01 BOLT_BRG_OUT_RR_10 BOLT_BRG_OUT_RR_11
fasteners | BOLT_CAM x4 | steel | - | UNVERIFIED | 4 | BOLT_CAM_0 BOLT_CAM_1 BOLT_CAM_2 BOLT_CAM_3
fasteners | BOLT_CARM x2 | steel | - | UNVERIFIED | 2 | BOLT_CARM_0 BOLT_CARM_1
fasteners | BOLT_CGRD x2 | steel | - | UNVERIFIED | 2 | BOLT_CGRD_0 BOLT_CGRD_1
fasteners | BOLT_CHEEK_L x4 | steel | - | UNVERIFIED | 4 | BOLT_CHEEK_L_0 BOLT_CHEEK_L_1 BOLT_CHEEK_L_2 BOLT_CHEEK_L_3
fasteners | BOLT_CHEEK_R x4 | steel | - | UNVERIFIED | 4 | BOLT_CHEEK_R_0 BOLT_CHEEK_R_1 BOLT_CHEEK_R_2 BOLT_CHEEK_R_3
fasteners | BOLT_CHK_L x3 | steel | - | UNVERIFIED | 3 | BOLT_CHK_L_0 BOLT_CHK_L_1 BOLT_CHK_L_2
fasteners | BOLT_CHK_R x3 | steel | - | UNVERIFIED | 3 | BOLT_CHK_R_0 BOLT_CHK_R_1 BOLT_CHK_R_2
fasteners | BOLT_CHP x2 | steel | - | UNVERIFIED | 2 | BOLT_CHP_0 BOLT_CHP_1
fasteners | BOLT_CHT x2 | steel | - | UNVERIFIED | 2 | BOLT_CHT_0 BOLT_CHT_1
fasteners | BOLT_CK_L0 | steel | - | UNVERIFIED | 1 | BOLT_CK_L0
fasteners | BOLT_CK_L1 | steel | - | UNVERIFIED | 1 | BOLT_CK_L1
fasteners | BOLT_CK_L2 | steel | - | UNVERIFIED | 1 | BOLT_CK_L2
fasteners | BOLT_CK_L3 | steel | - | UNVERIFIED | 1 | BOLT_CK_L3
fasteners | BOLT_CK_R0 | steel | - | UNVERIFIED | 1 | BOLT_CK_R0
fasteners | BOLT_CK_R1 | steel | - | UNVERIFIED | 1 | BOLT_CK_R1
fasteners | BOLT_CK_R2 | steel | - | UNVERIFIED | 1 | BOLT_CK_R2
fasteners | BOLT_CK_R3 | steel | - | UNVERIFIED | 1 | BOLT_CK_R3
fasteners | BOLT_CLMP_FL x4 | steel | - | UNVERIFIED | 4 | BOLT_CLMP_FL_0_0 BOLT_CLMP_FL_0_1 BOLT_CLMP_FL_1_0 BOLT_CLMP_FL_1_1
fasteners | BOLT_CLMP_FR x4 | steel | - | UNVERIFIED | 4 | BOLT_CLMP_FR_0_0 BOLT_CLMP_FR_0_1 BOLT_CLMP_FR_1_0 BOLT_CLMP_FR_1_1
fasteners | BOLT_CLMP_RL x4 | steel | - | UNVERIFIED | 4 | BOLT_CLMP_RL_0_0 BOLT_CLMP_RL_0_1 BOLT_CLMP_RL_1_0 BOLT_CLMP_RL_1_1
fasteners | BOLT_CLMP_RR x4 | steel | - | UNVERIFIED | 4 | BOLT_CLMP_RR_0_0 BOLT_CLMP_RR_0_1 BOLT_CLMP_RR_1_0 BOLT_CLMP_RR_1_1
fasteners | BOLT_COL x4 | steel | - | UNVERIFIED | 4 | BOLT_COL_0 BOLT_COL_1 BOLT_COL_2 BOLT_COL_3
fasteners | BOLT_COLB x4 | steel | - | UNVERIFIED | 4 | BOLT_COLB_0 BOLT_COLB_1 BOLT_COLB_2 BOLT_COLB_3
fasteners | BOLT_CPOSTF_L x4 | steel | - | UNVERIFIED | 4 | BOLT_CPOSTF_L_0 BOLT_CPOSTF_L_1 BOLT_CPOSTF_L_2 BOLT_CPOSTF_L_3
fasteners | BOLT_CPOSTF_R x4 | steel | - | UNVERIFIED | 4 | BOLT_CPOSTF_R_0 BOLT_CPOSTF_R_1 BOLT_CPOSTF_R_2 BOLT_CPOSTF_R_3
fasteners | BOLT_CROWN_L x2 | steel | - | UNVERIFIED | 2 | BOLT_CROWN_L_0 BOLT_CROWN_L_1
fasteners | BOLT_CROWN_R x2 | steel | - | UNVERIFIED | 2 | BOLT_CROWN_R_0 BOLT_CROWN_R_1
fasteners | BOLT_DP_B_L0 | steel | - | UNVERIFIED | 1 | BOLT_DP_B_L0
fasteners | BOLT_DP_B_L1 | steel | - | UNVERIFIED | 1 | BOLT_DP_B_L1
fasteners | BOLT_DP_B_L2 | steel | - | UNVERIFIED | 1 | BOLT_DP_B_L2
fasteners | BOLT_DP_B_L3 | steel | - | UNVERIFIED | 1 | BOLT_DP_B_L3
fasteners | BOLT_DP_B_R0 | steel | - | UNVERIFIED | 1 | BOLT_DP_B_R0
fasteners | BOLT_DP_B_R1 | steel | - | UNVERIFIED | 1 | BOLT_DP_B_R1
fasteners | BOLT_DP_B_R2 | steel | - | UNVERIFIED | 1 | BOLT_DP_B_R2
fasteners | BOLT_DP_B_R3 | steel | - | UNVERIFIED | 1 | BOLT_DP_B_R3
fasteners | BOLT_DP_T_L0 | steel | - | UNVERIFIED | 1 | BOLT_DP_T_L0
fasteners | BOLT_DP_T_L1 | steel | - | UNVERIFIED | 1 | BOLT_DP_T_L1
fasteners | BOLT_DP_T_L2 | steel | - | UNVERIFIED | 1 | BOLT_DP_T_L2
fasteners | BOLT_DP_T_L3 | steel | - | UNVERIFIED | 1 | BOLT_DP_T_L3
fasteners | BOLT_DP_T_R0 | steel | - | UNVERIFIED | 1 | BOLT_DP_T_R0
fasteners | BOLT_DP_T_R1 | steel | - | UNVERIFIED | 1 | BOLT_DP_T_R1
fasteners | BOLT_DP_T_R2 | steel | - | UNVERIFIED | 1 | BOLT_DP_T_R2
fasteners | BOLT_DP_T_R3 | steel | - | UNVERIFIED | 1 | BOLT_DP_T_R3
fasteners | BOLT_DVBR x4 | steel | - | UNVERIFIED | 4 | BOLT_DVBR_0 BOLT_DVBR_1 BOLT_DVBR_2 BOLT_DVBR_3
fasteners | BOLT_FBRG x4 | steel | - | UNVERIFIED | 4 | BOLT_FBRG_00 BOLT_FBRG_01 BOLT_FBRG_10 BOLT_FBRG_11
fasteners | BOLT_FBRG_L0 | steel | - | UNVERIFIED | 1 | BOLT_FBRG_L0
fasteners | BOLT_FBRG_L1 | steel | - | UNVERIFIED | 1 | BOLT_FBRG_L1
fasteners | BOLT_FBRG_L2 | steel | - | UNVERIFIED | 1 | BOLT_FBRG_L2
fasteners | BOLT_FBRG_L3 | steel | - | UNVERIFIED | 1 | BOLT_FBRG_L3
fasteners | BOLT_FBRG_R0 | steel | - | UNVERIFIED | 1 | BOLT_FBRG_R0
fasteners | BOLT_FBRG_R1 | steel | - | UNVERIFIED | 1 | BOLT_FBRG_R1
fasteners | BOLT_FBRG_R2 | steel | - | UNVERIFIED | 1 | BOLT_FBRG_R2
fasteners | BOLT_FBRG_R3 | steel | - | UNVERIFIED | 1 | BOLT_FBRG_R3
fasteners | BOLT_FMTR x4 | steel | - | UNVERIFIED | 4 | BOLT_FMTR_0 BOLT_FMTR_1 BOLT_FMTR_2 BOLT_FMTR_3
fasteners | BOLT_FM_L0 | steel | - | UNVERIFIED | 1 | BOLT_FM_L0
fasteners | BOLT_FM_L1 | steel | - | UNVERIFIED | 1 | BOLT_FM_L1
fasteners | BOLT_FM_L2 | steel | - | UNVERIFIED | 1 | BOLT_FM_L2
fasteners | BOLT_FM_L3 | steel | - | UNVERIFIED | 1 | BOLT_FM_L3
fasteners | BOLT_FM_R0 | steel | - | UNVERIFIED | 1 | BOLT_FM_R0
fasteners | BOLT_FM_R1 | steel | - | UNVERIFIED | 1 | BOLT_FM_R1
fasteners | BOLT_FM_R2 | steel | - | UNVERIFIED | 1 | BOLT_FM_R2
fasteners | BOLT_FM_R3 | steel | - | UNVERIFIED | 1 | BOLT_FM_R3
fasteners | BOLT_FSO x2 | steel | - | UNVERIFIED | 2 | BOLT_FSO_0 BOLT_FSO_1
fasteners | BOLT_GBRK x4 | steel | - | UNVERIFIED | 4 | BOLT_GBRK_0 BOLT_GBRK_1 BOLT_GBRK_2 BOLT_GBRK_3
fasteners | BOLT_GUD_L0 x2 | steel | - | UNVERIFIED | 2 | BOLT_GUD_L0_0 BOLT_GUD_L0_1
fasteners | BOLT_GUD_L1 x2 | steel | - | UNVERIFIED | 2 | BOLT_GUD_L1_0 BOLT_GUD_L1_1
fasteners | BOLT_GUD_R2 x2 | steel | - | UNVERIFIED | 2 | BOLT_GUD_R2_0 BOLT_GUD_R2_1
fasteners | BOLT_GUSU_L x2 | steel | - | UNVERIFIED | 2 | BOLT_GUSU_L_0_0 BOLT_GUSU_L_1_0
fasteners | BOLT_GUSU_R x2 | steel | - | UNVERIFIED | 2 | BOLT_GUSU_R_0_0 BOLT_GUSU_R_1_0
fasteners | BOLT_GUSU_XL x2 | steel | - | UNVERIFIED | 2 | BOLT_GUSU_XL_0 BOLT_GUSU_XL_1
fasteners | BOLT_GUSU_XR x2 | steel | - | UNVERIFIED | 2 | BOLT_GUSU_XR_0 BOLT_GUSU_XR_1
fasteners | BOLT_GUSX_L x2 | steel | - | UNVERIFIED | 2 | BOLT_GUSX_L_0 BOLT_GUSX_L_1
fasteners | BOLT_GUSX_R x2 | steel | - | UNVERIFIED | 2 | BOLT_GUSX_R_0 BOLT_GUSX_R_1
fasteners | BOLT_GUS_L x4 | steel | - | UNVERIFIED | 4 | BOLT_GUS_L_0_0 BOLT_GUS_L_0_1 BOLT_GUS_L_1_0 BOLT_GUS_L_1_1
fasteners | BOLT_GUS_L0 x2 | steel | - | UNVERIFIED | 2 | BOLT_GUS_L0_0 BOLT_GUS_L0_1
fasteners | BOLT_GUS_L1 x2 | steel | - | UNVERIFIED | 2 | BOLT_GUS_L1_0 BOLT_GUS_L1_1
fasteners | BOLT_GUS_R x4 | steel | - | UNVERIFIED | 4 | BOLT_GUS_R_0_0 BOLT_GUS_R_0_1 BOLT_GUS_R_1_0 BOLT_GUS_R_1_1
fasteners | BOLT_GUS_R2 x2 | steel | - | UNVERIFIED | 2 | BOLT_GUS_R2_0 BOLT_GUS_R2_1
fasteners | BOLT_GUS_R3 x2 | steel | - | UNVERIFIED | 2 | BOLT_GUS_R3_0 BOLT_GUS_R3_1
fasteners | BOLT_HBRKF_L x2 | steel | - | UNVERIFIED | 2 | BOLT_HBRKF_L_0 BOLT_HBRKF_L_1
fasteners | BOLT_HBRKF_R x2 | steel | - | UNVERIFIED | 2 | BOLT_HBRKF_R_0 BOLT_HBRKF_R_1
fasteners | BOLT_HBRK_L x4 | steel | - | UNVERIFIED | 4 | BOLT_HBRK_L_0_0 BOLT_HBRK_L_0_1 BOLT_HBRK_L_1_0 BOLT_HBRK_L_1_1
fasteners | BOLT_HBRK_R x4 | steel | - | UNVERIFIED | 4 | BOLT_HBRK_R_0_0 BOLT_HBRK_R_0_1 BOLT_HBRK_R_1_0 BOLT_HBRK_R_1_1
fasteners | BOLT_HLDG_L x3 | steel | - | UNVERIFIED | 3 | BOLT_HLDG_L_0 BOLT_HLDG_L_1 BOLT_HLDG_L_2
fasteners | BOLT_HLDG_R x3 | steel | - | UNVERIFIED | 3 | BOLT_HLDG_R_0 BOLT_HLDG_R_1 BOLT_HLDG_R_2
fasteners | BOLT_HUB_C x4 | steel | - | UNVERIFIED | 4 | BOLT_HUB_C_0 BOLT_HUB_C_1 BOLT_HUB_C_2 BOLT_HUB_C_3
fasteners | BOLT_HUB_E x4 | steel | - | UNVERIFIED | 4 | BOLT_HUB_E_0 BOLT_HUB_E_1 BOLT_HUB_E_2 BOLT_HUB_E_3
fasteners | BOLT_IBRG_L x4 | steel | - | UNVERIFIED | 4 | BOLT_IBRG_L_00 BOLT_IBRG_L_01 BOLT_IBRG_L_10 BOLT_IBRG_L_11
fasteners | BOLT_IBRG_R x4 | steel | - | UNVERIFIED | 4 | BOLT_IBRG_R_00 BOLT_IBRG_R_01 BOLT_IBRG_R_10 BOLT_IBRG_R_11
fasteners | BOLT_IMP x8 | steel | - | UNVERIFIED | 8 | BOLT_IMP_0 BOLT_IMP_1 BOLT_IMP_2 BOLT_IMP_3 BOLT_IMP_4 BOLT_IMP_5 BOLT_IMP_6 BOLT_IMP_7
fasteners | BOLT_IMTR x4 | steel | - | UNVERIFIED | 4 | BOLT_IMTR_00 BOLT_IMTR_01 BOLT_IMTR_10 BOLT_IMTR_11
fasteners | BOLT_LB x4 | steel | - | UNVERIFIED | 4 | BOLT_LB_0 BOLT_LB_1 BOLT_LB_2 BOLT_LB_3
fasteners | BOLT_LRF_L0 | steel | - | UNVERIFIED | 1 | BOLT_LRF_L0
fasteners | BOLT_LRF_L1 | steel | - | UNVERIFIED | 1 | BOLT_LRF_L1
fasteners | BOLT_LRF_R0 | steel | - | UNVERIFIED | 1 | BOLT_LRF_R0
fasteners | BOLT_LRF_R1 | steel | - | UNVERIFIED | 1 | BOLT_LRF_R1
fasteners | BOLT_LTT_L0 | steel | - | UNVERIFIED | 1 | BOLT_LTT_L0
fasteners | BOLT_LTT_L1 | steel | - | UNVERIFIED | 1 | BOLT_LTT_L1
fasteners | BOLT_LTT_R0 | steel | - | UNVERIFIED | 1 | BOLT_LTT_R0
fasteners | BOLT_LTT_R1 | steel | - | UNVERIFIED | 1 | BOLT_LTT_R1
fasteners | BOLT_LW x4 | steel | - | UNVERIFIED | 4 | BOLT_LW_0 BOLT_LW_1 BOLT_LW_2 BOLT_LW_3
fasteners | BOLT_MCL_L0 | steel | - | UNVERIFIED | 1 | BOLT_MCL_L0
fasteners | BOLT_MCL_L1 | steel | - | UNVERIFIED | 1 | BOLT_MCL_L1
fasteners | BOLT_MCL_R0 | steel | - | UNVERIFIED | 1 | BOLT_MCL_R0
fasteners | BOLT_MCL_R1 | steel | - | UNVERIFIED | 1 | BOLT_MCL_R1
fasteners | BOLT_MPL_L x12 | steel | - | UNVERIFIED | 12 | BOLT_MPL_L_0 BOLT_MPL_L_1 BOLT_MPL_L_2 BOLT_MPL_L_3 BOLT_MPL_L_4 BOLT_MPL_L_5 BOLT_MPL_L_6 BOLT_MPL_L_7 BOLT_MPL_L_8 BOLT_MPL_L_9 BOLT_MPL_L_10 BOLT_MPL_L_11
fasteners | BOLT_MPL_R x12 | steel | - | UNVERIFIED | 12 | BOLT_MPL_R_0 BOLT_MPL_R_1 BOLT_MPL_R_2 BOLT_MPL_R_3 BOLT_MPL_R_4 BOLT_MPL_R_5 BOLT_MPL_R_6 BOLT_MPL_R_7 BOLT_MPL_R_8 BOLT_MPL_R_9 BOLT_MPL_R_10 BOLT_MPL_R_11
fasteners | BOLT_MTR_FL x4 | steel | - | UNVERIFIED | 4 | BOLT_MTR_FL_00 BOLT_MTR_FL_01 BOLT_MTR_FL_10 BOLT_MTR_FL_11
fasteners | BOLT_MTR_FR x4 | steel | - | UNVERIFIED | 4 | BOLT_MTR_FR_00 BOLT_MTR_FR_01 BOLT_MTR_FR_10 BOLT_MTR_FR_11
fasteners | BOLT_MTR_RL x4 | steel | - | UNVERIFIED | 4 | BOLT_MTR_RL_00 BOLT_MTR_RL_01 BOLT_MTR_RL_10 BOLT_MTR_RL_11
fasteners | BOLT_MTR_RR x4 | steel | - | UNVERIFIED | 4 | BOLT_MTR_RR_00 BOLT_MTR_RR_01 BOLT_MTR_RR_10 BOLT_MTR_RR_11
fasteners | BOLT_NBP x4 | steel | - | UNVERIFIED | 4 | BOLT_NBP_0 BOLT_NBP_1 BOLT_NBP_2 BOLT_NBP_3
fasteners | BOLT_NUM_B x4 | steel | - | UNVERIFIED | 4 | BOLT_NUM_B_0 BOLT_NUM_B_1 BOLT_NUM_B_2 BOLT_NUM_B_3
fasteners | BOLT_NUM_L x4 | steel | - | UNVERIFIED | 4 | BOLT_NUM_L_0 BOLT_NUM_L_1 BOLT_NUM_L_2 BOLT_NUM_L_3
fasteners | BOLT_ODO_LAT_L x2 | steel | - | UNVERIFIED | 2 | BOLT_ODO_LAT_L_0 BOLT_ODO_LAT_L_1
fasteners | BOLT_ODO_LAT_R x2 | steel | - | UNVERIFIED | 2 | BOLT_ODO_LAT_R_0 BOLT_ODO_LAT_R_1
fasteners | BOLT_ODO_LON x2 | steel | - | UNVERIFIED | 2 | BOLT_ODO_LON_0 BOLT_ODO_LON_1
fasteners | BOLT_PANB_L0 x2 | steel | - | UNVERIFIED | 2 | BOLT_PANB_L0_0 BOLT_PANB_L0_1
fasteners | BOLT_PANB_L1 x2 | steel | - | UNVERIFIED | 2 | BOLT_PANB_L1_0 BOLT_PANB_L1_1
fasteners | BOLT_PANB_L2 x2 | steel | - | UNVERIFIED | 2 | BOLT_PANB_L2_0 BOLT_PANB_L2_1
fasteners | BOLT_PANB_R0 x2 | steel | - | UNVERIFIED | 2 | BOLT_PANB_R0_0 BOLT_PANB_R0_1
fasteners | BOLT_PANB_R1 x2 | steel | - | UNVERIFIED | 2 | BOLT_PANB_R1_0 BOLT_PANB_R1_1
fasteners | BOLT_PANB_R2 x2 | steel | - | UNVERIFIED | 2 | BOLT_PANB_R2_0 BOLT_PANB_R2_1
fasteners | BOLT_PANF_L0 | steel | - | UNVERIFIED | 1 | BOLT_PANF_L0
fasteners | BOLT_PANF_L1 | steel | - | UNVERIFIED | 1 | BOLT_PANF_L1
fasteners | BOLT_PANF_L2 | steel | - | UNVERIFIED | 1 | BOLT_PANF_L2
fasteners | BOLT_PANF_R0 | steel | - | UNVERIFIED | 1 | BOLT_PANF_R0
fasteners | BOLT_PANF_R1 | steel | - | UNVERIFIED | 1 | BOLT_PANF_R1
fasteners | BOLT_PANF_R2 | steel | - | UNVERIFIED | 1 | BOLT_PANF_R2
fasteners | BOLT_PORT x4 | steel | - | UNVERIFIED | 4 | BOLT_PORT_0 BOLT_PORT_1 BOLT_PORT_2 BOLT_PORT_3
fasteners | BOLT_RING x4 | steel | - | UNVERIFIED | 4 | BOLT_RING_0 BOLT_RING_1 BOLT_RING_2 BOLT_RING_3
fasteners | BOLT_S1TIE x4 | steel | - | UNVERIFIED | 4 | BOLT_S1TIE_0 BOLT_S1TIE_1 BOLT_S1TIE_2 BOLT_S1TIE_3
fasteners | BOLT_S2TIE x3 | steel | - | UNVERIFIED | 3 | BOLT_S2TIE_0 BOLT_S2TIE_1 BOLT_S2TIE_2
fasteners | BOLT_SC_L0 | steel | - | UNVERIFIED | 1 | BOLT_SC_L0
fasteners | BOLT_SC_L1 | steel | - | UNVERIFIED | 1 | BOLT_SC_L1
fasteners | BOLT_SC_R0 | steel | - | UNVERIFIED | 1 | BOLT_SC_R0
fasteners | BOLT_SC_R1 | steel | - | UNVERIFIED | 1 | BOLT_SC_R1
fasteners | BOLT_SHI x4 | steel | - | UNVERIFIED | 4 | BOLT_SHI_0 BOLT_SHI_1 BOLT_SHI_2 BOLT_SHI_3
fasteners | BOLT_SLO x4 | steel | - | UNVERIFIED | 4 | BOLT_SLO_0 BOLT_SLO_1 BOLT_SLO_2 BOLT_SLO_3
fasteners | BOLT_SO_B x4 | steel | - | UNVERIFIED | 4 | BOLT_SO_B_0 BOLT_SO_B_1 BOLT_SO_B_2 BOLT_SO_B_3
fasteners | BOLT_SO_T x4 | steel | - | UNVERIFIED | 4 | BOLT_SO_T_0 BOLT_SO_T_1 BOLT_SO_T_2 BOLT_SO_T_3
fasteners | BOLT_STRAP x4 | steel | - | UNVERIFIED | 4 | BOLT_STRAP_0_0 BOLT_STRAP_0_1 BOLT_STRAP_1_0 BOLT_STRAP_1_1
fasteners | BOLT_SW x2 | steel | - | UNVERIFIED | 2 | BOLT_SW_0 BOLT_SW_1
fasteners | BOLT_TBR x2 | steel | - | UNVERIFIED | 2 | BOLT_TBR_0 BOLT_TBR_1
fasteners | BOLT_THRT x4 | steel | - | UNVERIFIED | 4 | BOLT_THRT_0 BOLT_THRT_1 BOLT_THRT_2 BOLT_THRT_3
fasteners | BOLT_TIE_L x4 | steel | - | UNVERIFIED | 4 | BOLT_TIE_L_0 BOLT_TIE_L_1 BOLT_TIE_L_2 BOLT_TIE_L_3
fasteners | BOLT_TIE_R x4 | steel | - | UNVERIFIED | 4 | BOLT_TIE_R_0 BOLT_TIE_R_1 BOLT_TIE_R_2 BOLT_TIE_R_3
fasteners | BOLT_TWC_L x4 | steel | - | UNVERIFIED | 4 | BOLT_TWC_L_0 BOLT_TWC_L_1 BOLT_TWC_L_2 BOLT_TWC_L_3
fasteners | BOLT_TWC_R x4 | steel | - | UNVERIFIED | 4 | BOLT_TWC_R_0 BOLT_TWC_R_1 BOLT_TWC_R_2 BOLT_TWC_R_3
fasteners | BOLT_TWF_L x4 | steel | - | UNVERIFIED | 4 | BOLT_TWF_L_0 BOLT_TWF_L_1 BOLT_TWF_L_2 BOLT_TWF_L_3
fasteners | BOLT_TWF_R x4 | steel | - | UNVERIFIED | 4 | BOLT_TWF_R_0 BOLT_TWF_R_1 BOLT_TWF_R_2 BOLT_TWF_R_3
fasteners | BOLT_YTR x4 | steel | - | UNVERIFIED | 4 | BOLT_YTR_0 BOLT_YTR_1 BOLT_YTR_2 BOLT_YTR_3
fasteners | NUT_AGBRK x4 | steel | - | UNVERIFIED | 4 | NUT_AGBRK_0 NUT_AGBRK_1 NUT_AGBRK_2 NUT_AGBRK_3
fasteners | NUT_CAM x4 | steel | - | UNVERIFIED | 4 | NUT_CAM_0 NUT_CAM_1 NUT_CAM_2 NUT_CAM_3
fasteners | NUT_CGRD x2 | steel | - | UNVERIFIED | 2 | NUT_CGRD_0 NUT_CGRD_1
fasteners | NUT_CHK_L x3 | steel | - | UNVERIFIED | 3 | NUT_CHK_L_0 NUT_CHK_L_1 NUT_CHK_L_2
fasteners | NUT_CHK_R x3 | steel | - | UNVERIFIED | 3 | NUT_CHK_R_0 NUT_CHK_R_1 NUT_CHK_R_2
fasteners | NUT_CHT x2 | steel | - | UNVERIFIED | 2 | NUT_CHT_0 NUT_CHT_1
fasteners | NUT_CK_L0 | steel | - | UNVERIFIED | 1 | NUT_CK_L0
fasteners | NUT_CK_L1 | steel | - | UNVERIFIED | 1 | NUT_CK_L1
fasteners | NUT_CK_L2 | steel | - | UNVERIFIED | 1 | NUT_CK_L2
fasteners | NUT_CK_L3 | steel | - | UNVERIFIED | 1 | NUT_CK_L3
fasteners | NUT_CK_R0 | steel | - | UNVERIFIED | 1 | NUT_CK_R0
fasteners | NUT_CK_R1 | steel | - | UNVERIFIED | 1 | NUT_CK_R1
fasteners | NUT_CK_R2 | steel | - | UNVERIFIED | 1 | NUT_CK_R2
fasteners | NUT_CK_R3 | steel | - | UNVERIFIED | 1 | NUT_CK_R3
fasteners | NUT_CLMP_FL x4 | steel | - | UNVERIFIED | 4 | NUT_CLMP_FL_0_0 NUT_CLMP_FL_0_1 NUT_CLMP_FL_1_0 NUT_CLMP_FL_1_1
fasteners | NUT_CLMP_FR x4 | steel | - | UNVERIFIED | 4 | NUT_CLMP_FR_0_0 NUT_CLMP_FR_0_1 NUT_CLMP_FR_1_0 NUT_CLMP_FR_1_1
fasteners | NUT_CLMP_RL x4 | steel | - | UNVERIFIED | 4 | NUT_CLMP_RL_0_0 NUT_CLMP_RL_0_1 NUT_CLMP_RL_1_0 NUT_CLMP_RL_1_1
fasteners | NUT_CLMP_RR x4 | steel | - | UNVERIFIED | 4 | NUT_CLMP_RR_0_0 NUT_CLMP_RR_0_1 NUT_CLMP_RR_1_0 NUT_CLMP_RR_1_1
fasteners | NUT_CPOSTF_L x4 | steel | - | UNVERIFIED | 4 | NUT_CPOSTF_L_0 NUT_CPOSTF_L_1 NUT_CPOSTF_L_2 NUT_CPOSTF_L_3
fasteners | NUT_CPOSTF_R x4 | steel | - | UNVERIFIED | 4 | NUT_CPOSTF_R_0 NUT_CPOSTF_R_1 NUT_CPOSTF_R_2 NUT_CPOSTF_R_3
fasteners | NUT_CROWN_L x2 | steel | - | UNVERIFIED | 2 | NUT_CROWN_L_0 NUT_CROWN_L_1
fasteners | NUT_CROWN_R x2 | steel | - | UNVERIFIED | 2 | NUT_CROWN_R_0 NUT_CROWN_R_1
fasteners | NUT_GBRK x4 | steel | - | UNVERIFIED | 4 | NUT_GBRK_0 NUT_GBRK_1 NUT_GBRK_2 NUT_GBRK_3
fasteners | NUT_GUD_L0 x2 | steel | - | UNVERIFIED | 2 | NUT_GUD_L0_0 NUT_GUD_L0_1
fasteners | NUT_GUD_L1 x2 | steel | - | UNVERIFIED | 2 | NUT_GUD_L1_0 NUT_GUD_L1_1
fasteners | NUT_GUD_R2 x2 | steel | - | UNVERIFIED | 2 | NUT_GUD_R2_0 NUT_GUD_R2_1
fasteners | NUT_GUSU_L x2 | steel | - | UNVERIFIED | 2 | NUT_GUSU_L_0_0 NUT_GUSU_L_1_0
fasteners | NUT_GUSU_R x2 | steel | - | UNVERIFIED | 2 | NUT_GUSU_R_0_0 NUT_GUSU_R_1_0
fasteners | NUT_GUSU_XL x2 | steel | - | UNVERIFIED | 2 | NUT_GUSU_XL_0 NUT_GUSU_XL_1
fasteners | NUT_GUSU_XR x2 | steel | - | UNVERIFIED | 2 | NUT_GUSU_XR_0 NUT_GUSU_XR_1
fasteners | NUT_GUSX_L x2 | steel | - | UNVERIFIED | 2 | NUT_GUSX_L_0 NUT_GUSX_L_1
fasteners | NUT_GUSX_R x2 | steel | - | UNVERIFIED | 2 | NUT_GUSX_R_0 NUT_GUSX_R_1
fasteners | NUT_GUS_L x4 | steel | - | UNVERIFIED | 4 | NUT_GUS_L_0_0 NUT_GUS_L_0_1 NUT_GUS_L_1_0 NUT_GUS_L_1_1
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

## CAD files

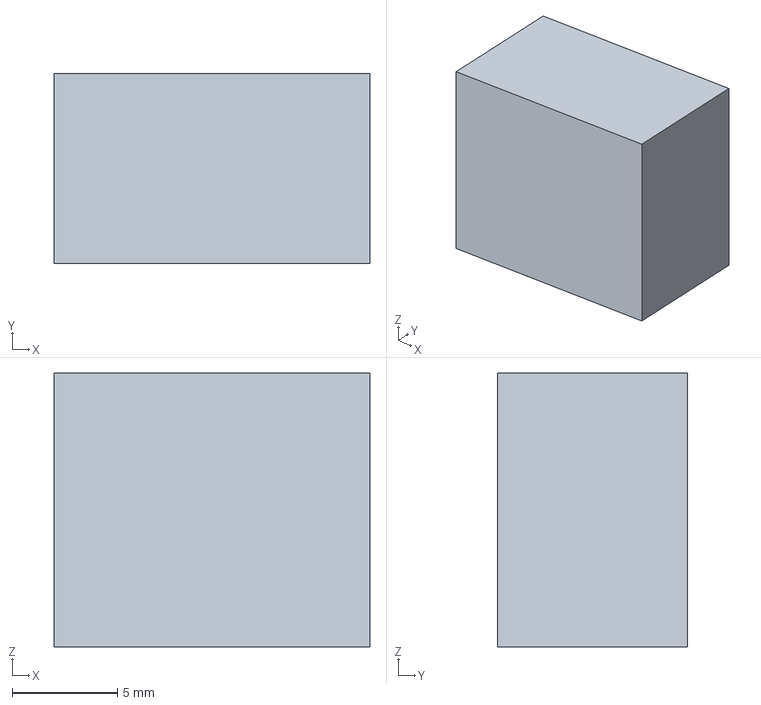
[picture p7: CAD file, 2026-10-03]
exports/step/parts/MAIN_SWITCH.step
15.0 x 9.00 x 13.0 mm

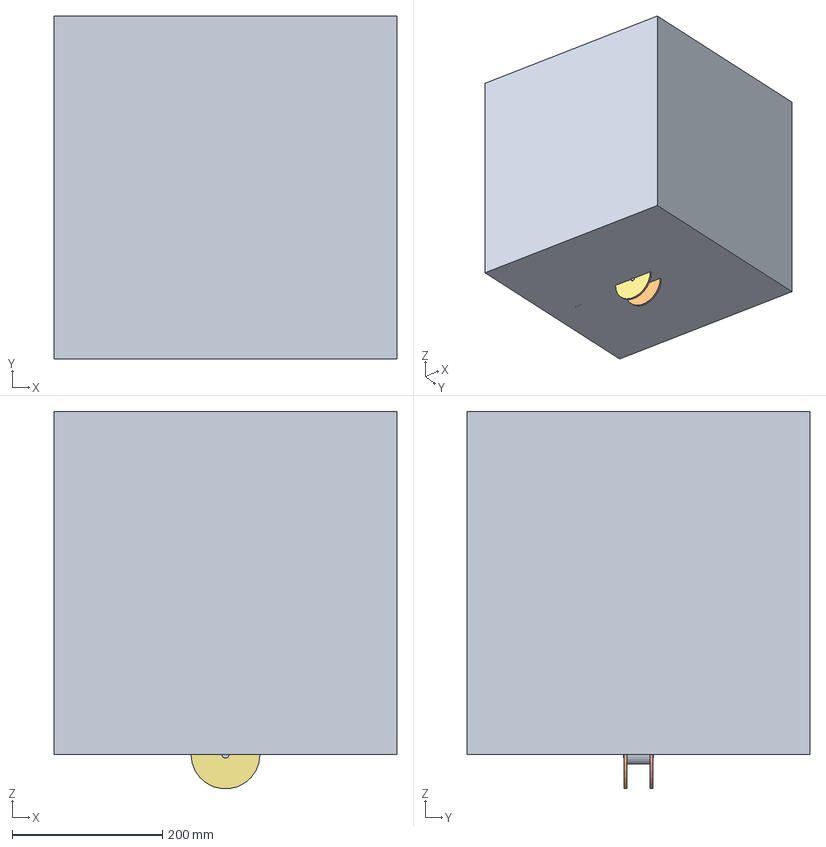
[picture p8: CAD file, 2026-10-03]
cad/drivebase/drivebase.FCStd
457.2 x 457.2 x 502.9 mm
ENV_START_457.2cube_VERIFIED
MOUNT_PLATE_L_motorplate_UNVERIFIED
MOUNT_PLATE_R_motorplate_UNVERIFIED
WHEEL_HUB_FL_O26_hexbore_VENDOR-PENDING
WHEEL_PLATE_FL_IN_O92_VENDOR-PENDING
WHEEL_PLATE_FL_OUT_O92_VENDOR-PENDING
ROLLER_FL_00_B_O14_roller_axle_pin_VENDOR-PENDING
ROLLER_FL_01_B_O14_roller_axle_pin_VENDOR-PENDING
ROLLER_FL_02_B_O14_roller_axle_pin_VENDOR-PENDING
ROLLER_FL_03_B_O14_roller_axle_pin_VENDOR-PENDING
ROLLER_FL_04_B_O14_roller_axle_pin_VENDOR-PENDING
ROLLER_FL_05_B_O14_roller_axle_pin_VENDOR-PENDING
ROLLER_FL_06_B_O14_roller_axle_pin_VENDOR-PENDING
ROLLER_FL_07_B_O14_roller_axle_pin_VENDOR-PENDING
ROLLER_FL_08_B_O14_roller_axle_pin_VENDOR-PENDING
ROLLER_FL_09_B_O14_roller_axle_pin_VENDOR-PENDING
BOLT_HUB_FL_M4_pinch_UNVERIFIED
AXLE_FL_8mmREX_M8tip_VENDOR-PENDING
BRG_IN_FL_flangeblock_26x6_VENDOR-PENDING
BRG_OUT_FL_flangeblock_26x6_VENDOR-PENDING
MOTOR_FL_5203class_gb_VENDOR-PENDING
WSH_AXLE_FL_O16_UNVERIFIED
COLLAR_FL_O18_UNVERIFIED
PINION_FL_15T_hub_UNVERIFIED
NUT_AXLE_FL_M8nylock_UNVERIFIED
CLAMP_FL_2_splitring_UNVERIFIED
CLAMP_FL_1_splitring_UNVERIFIED
WHEEL_HUB_FR_O26_hexbore_VENDOR-PENDING
WHEEL_PLATE_FR_IN_O92_VENDOR-PENDING
WHEEL_PLATE_FR_OUT_O92_VENDOR-PENDING
ROLLER_FR_00_B_O14_roller_axle_pin_VENDOR-PENDING
ROLLER_FR_01_B_O14_roller_axle_pin_VENDOR-PENDING
ROLLER_FR_02_B_O14_roller_axle_pin_VENDOR-PENDING
ROLLER_FR_03_B_O14_roller_axle_pin_VENDOR-PENDING
ROLLER_FR_04_B_O14_roller_axle_pin_VENDOR-PENDING
ROLLER_FR_05_B_O14_roller_axle_pin_VENDOR-PENDING
ROLLER_FR_06_B_O14_roller_axle_pin_VENDOR-PENDING
ROLLER_FR_07_B_O14_roller_axle_pin_VENDOR-PENDING
ROLLER_FR_08_B_O14_roller_axle_pin_VENDOR-PENDING
ROLLER_FR_09_B_O14_roller_axle_pin_VENDOR-PENDING
BOLT_HUB_FR_M4_pinch_UNVERIFIED
AXLE_FR_8mmREX_M8tip_VENDOR-PENDING
BRG_IN_FR_flangeblock_26x6_VENDOR-PENDING
BRG_OUT_FR_flangeblock_26x6_VENDOR-PENDING
MOTOR_FR_5203class_gb_VENDOR-PENDING
WSH_AXLE_FR_O16_UNVERIFIED
COLLAR_FR_O18_UNVERIFIED
PINION_FR_15T_hub_UNVERIFIED
NUT_AXLE_FR_M8nylock_UNVERIFIED
CLAMP_FR_2_splitring_UNVERIFIED
CLAMP_FR_1_splitring_UNVERIFIED
WHEEL_HUB_RL_O26_hexbore_VENDOR-PENDING
WHEEL_PLATE_RL_IN_O92_VENDOR-PENDING
WHEEL_PLATE_RL_OUT_O92_VENDOR-PENDING
ROLLER_RL_00_B_O14_roller_axle_pin_VENDOR-PENDING
ROLLER_RL_01_B_O14_roller_axle_pin_VENDOR-PENDING
ROLLER_RL_02_B_O14_roller_axle_pin_VENDOR-PENDING
ROLLER_RL_03_B_O14_roller_axle_pin_VENDOR-PENDING
ROLLER_RL_04_B_O14_roller_axle_pin_VENDOR-PENDING
ROLLER_RL_05_B_O14_roller_axle_pin_VENDOR-PENDING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

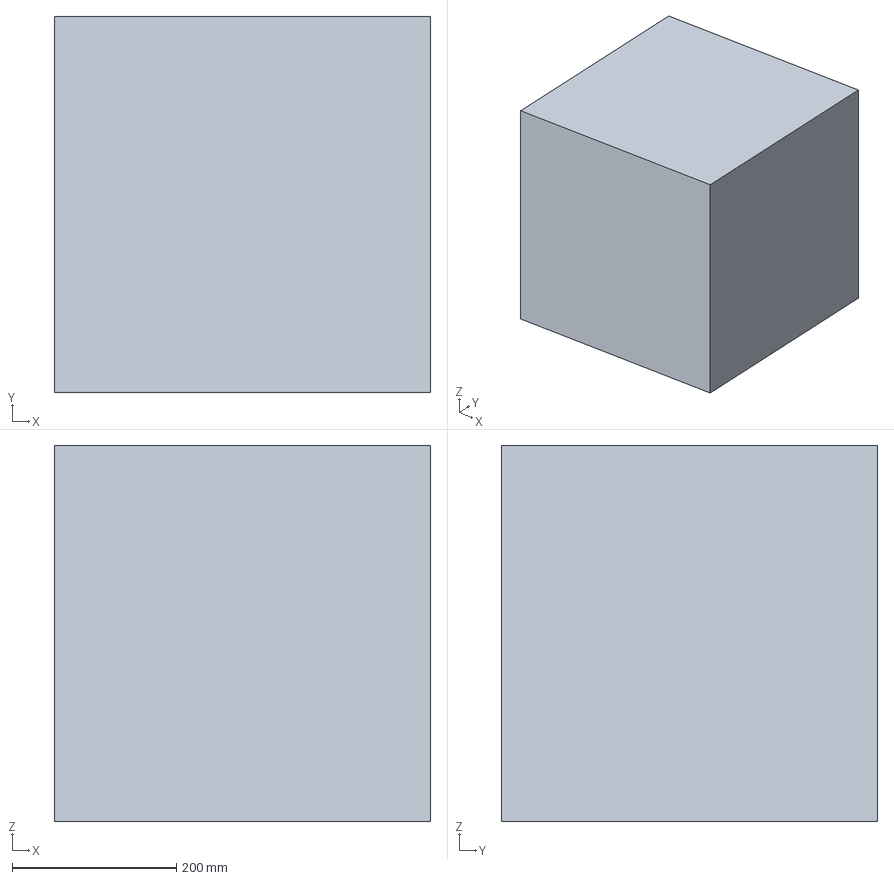
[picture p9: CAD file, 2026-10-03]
cad/electronics/electronics.FCStd
457.2 x 457.2 x 457.2 mm
ENV_START_457.2cube_VERIFIED
FRAME_RAIL_L_gobilda1120_invU_444.5_VENDOR-PENDING
FRAME_RAIL_R_gobilda1120_invU_444.5_VENDOR-PENDING
BELLY_PAN_sheet_UNVERIFIED
PAN_BRKT_L0_Lbracket_UNVERIFIED
PAN_BRKT_L1_Lbracket_UNVERIFIED
PAN_BRKT_L2_Lbracket_UNVERIFIED
PAN_BRKT_R0_Lbracket_UNVERIFIED
PAN_BRKT_R1_Lbracket_UNVERIFIED
PAN_BRKT_R2_Lbracket_UNVERIFIED
BATTERY_3000mAh_pack_VENDOR-PENDING
BATT_STRAP_0_strap_UNVERIFIED
BATT_STRAP_1_strap_UNVERIFIED
ELEC_SHELF_tray_UNVERIFIED
STANDOFF_0_standoff_UNVERIFIED
STANDOFF_1_standoff_UNVERIFIED
STANDOFF_2_standoff_UNVERIFIED
STANDOFF_3_standoff_UNVERIFIED
SWITCH_BRKT_Lbracket_UNVERIFIED
MAIN_SWITCH_toggle_UNVERIFIED
SCRW_SW_0_M3_selftap_UNVERIFIED
SCRW_SW_1_M3_selftap_UNVERIFIED
HUB_CTRL_hubfeet_VENDOR-PENDING
HUB_EXP_railmount_VENDOR-PENDING
WIRE_BATT_SW_wirerun_UNVERIFIED
WIRE_SW_CTRL_wirerun_UNVERIFIED
WIRE_HUB_RS485_wirerun_UNVERIFIED
WIRE_MTR_FL_wirerun_UNVERIFIED
WIRE_MTR_RL_wirerun_UNVERIFIED
WIRE_MTR_FR_wirerun_UNVERIFIED
WIRE_MTR_RR_wirerun_UNVERIFIED
WIRE_ENC_LAT_L_wirerun_UNVERIFIED
WIRE_ENC_LAT_R_wirerun_UNVERIFIED
WIRE_ENC_LON_wirerun_UNVERIFIED
CLIP_0_cableclip_UNVERIFIED
CLIP_1_cableclip_UNVERIFIED
CLIP_2_cableclip_UNVERIFIED
CLIP_3_cableclip_UNVERIFIED
BOLT_PANB_L0_0_M4_UNVERIFIED
NUT_PANB_L0_0_M4_UNVERIFIED
BOLT_PANB_L0_1_M4_UNVERIFIED
NUT_PANB_L0_1_M4_UNVERIFIED
BOLT_PANF_L0_M4_UNVERIFIED
NUT_PANF_L0_M4_UNVERIFIED
BOLT_PANB_L1_0_M4_UNVERIFIED
NUT_PANB_L1_0_M4_UNVERIFIED
BOLT_PANB_L1_1_M4_UNVERIFIED
NUT_PANB_L1_1_M4_UNVERIFIED
BOLT_PANF_L1_M4_UNVERIFIED
NUT_PANF_L1_M4_UNVERIFIED
BOLT_PANB_L2_0_M4_UNVERIFIED
NUT_PANB_L2_0_M4_UNVERIFIED
BOLT_PANB_L2_1_M4_UNVERIFIED
NUT_PANB_L2_1_M4_UNVERIFIED
BOLT_PANF_L2_M4_UNVERIFIED
NUT_PANF_L2_M4_UNVERIFIED
BOLT_PANB_R0_0_M4_UNVERIFIED
NUT_PANB_R0_0_M4_UNVERIFIED
BOLT_PANB_R0_1_M4_UNVERIFIED
NUT_PANB_R0_1_M4_UNVERIFIED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

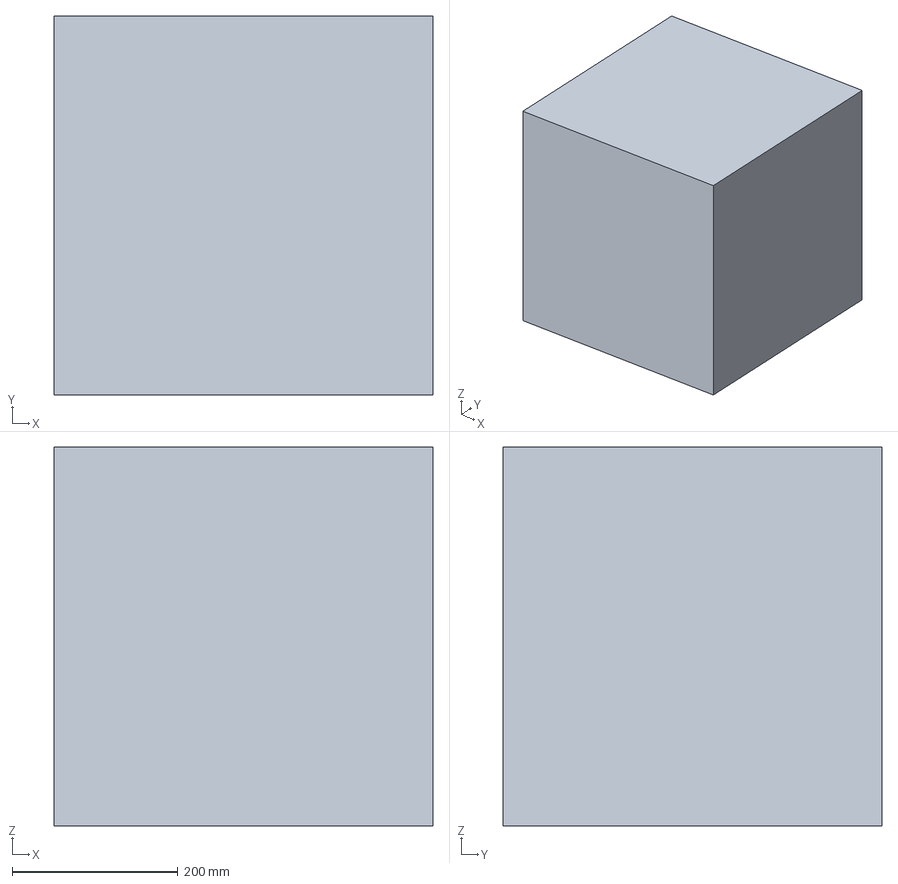
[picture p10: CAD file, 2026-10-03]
cad/hopper/hopper.FCStd
457.2 x 457.2 x 457.2 mm
ENV_START_457.2cube_VERIFIED
MOUNT_PLATE_L_motorplate_UNVERIFIED
MOUNT_PLATE_R_motorplate_UNVERIFIED
FRAME_RAIL_L_gobilda1120_invU_444.5_VENDOR-PENDING
FRAME_RAIL_R_gobilda1120_invU_444.5_VENDOR-PENDING
FRAME_CROSS_B_invU_271.8_VENDOR-PENDING
FRAME_CROWN_F_invU_271.8_raised_VENDOR-PENDING
CROWN_POST_L_post_UNVERIFIED
GUSSET_BL_Lgusset_40x40_UNVERIFIED
GUSSET_UL_Lgusset_low_UNVERIFIED
TIE_RB_L_splice_30x72x3_UNVERIFIED
CROWN_POST_R_post_UNVERIFIED
GUSSET_BR_Lgusset_40x40_UNVERIFIED
GUSSET_UR_Lgusset_low_UNVERIFIED
TIE_RB_R_splice_30x72x3_UNVERIFIED
BELLY_PAN_sheet_UNVERIFIED
PAN_BRKT_L0_Lbracket_UNVERIFIED
PAN_BRKT_L1_Lbracket_UNVERIFIED
PAN_BRKT_L2_Lbracket_UNVERIFIED
PAN_BRKT_R0_Lbracket_UNVERIFIED
PAN_BRKT_R1_Lbracket_UNVERIFIED
PAN_BRKT_R2_Lbracket_UNVERIFIED
DECK_L_deck_panel_UNVERIFIED
DECK_POST_L0_hexstandoff_O10_UNVERIFIED
DECK_POST_L1_hexstandoff_O10_UNVERIFIED
DECK_POST_L2_hexstandoff_O10_UNVERIFIED
DECK_POST_L3_hexstandoff_O10_UNVERIFIED
DECK_R_deck_panel_UNVERIFIED
DECK_POST_R0_hexstandoff_O10_UNVERIFIED
DECK_POST_R1_hexstandoff_O10_UNVERIFIED
DECK_POST_R2_hexstandoff_O10_UNVERIFIED
DECK_POST_R3_hexstandoff_O10_UNVERIFIED
ENDCAP_FL_endplug_UNVERIFIED
ENDCAP_BL_endplug_UNVERIFIED
ENDCAP_FR_endplug_UNVERIFIED
ENDCAP_BR_endplug_UNVERIFIED
ENDCAP_XB_L_endplug_UNVERIFIED
ENDCAP_XB_R_endplug_UNVERIFIED
PLATE_NUM_L_alliance_plate_UNVERIFIED
PLATE_NUM_B_alliance_plate_UNVERIFIED
HOP_FLOOR_3mm_20deg_UNVERIFIED
HOP_APRON_3mm_UNVERIFIED
HOP_WALL_L_3mm_UNVERIFIED
HOP_WALL_R_3mm_UNVERIFIED
HOP_LEDGE_L_3mm_UNVERIFIED
HOP_LEDGE_R_3mm_UNVERIFIED
HOP_CURB_3mm_UNVERIFIED
HOP_BRKT_L_0_incorner_UNVERIFIED
HOP_BRKT_L_1_incorner_UNVERIFIED
HOP_BRKT_R_0_incorner_UNVERIFIED
HOP_BRKT_R_1_incorner_UNVERIFIED
AGIT_BRKT_alu_UNVERIFIED
AGIT_SERVO_servo_UNVERIFIED
AGIT_HORN_spline_UNVERIFIED
AGIT_PADDLE_3armPETG_UNVERIFIED
FEED_WHEEL_greencompliant_VENDOR-PENDING
FEED_SHAFT_REX_UNVERIFIED
FEED_WALL_BRG_flg8mm_UNVERIFIED
FEED_MOTOR_5203compact_VENDOR-PENDING
FEED_MTR_PLATE_alu_UNVERIFIED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

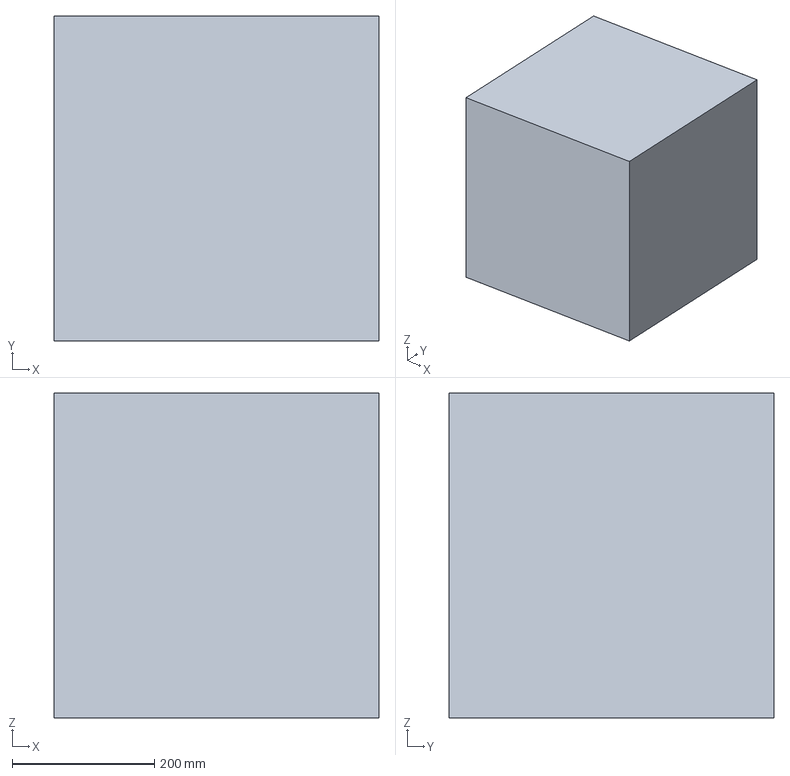
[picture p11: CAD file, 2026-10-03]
cad/intake/intake.FCStd
457.2 x 457.2 x 457.2 mm
ENV_START_457.2cube_VERIFIED
INT_CHEEK_L_5mmPETG_UNVERIFIED
FLOAT_SLIDE_L_acetal_UNVERIFIED
FLOAT_PIN_L_O4_UNVERIFIED
SPRING_POST_L_O8_UNVERIFIED
TORSION_SPRING_L_torsionspring_UNVERIFIED
INT_CHEEK_R_5mmPETG_UNVERIFIED
FLOAT_SLIDE_R_acetal_UNVERIFIED
FLOAT_PIN_R_O4_UNVERIFIED
SPRING_POST_R_O8_UNVERIFIED
TORSION_SPRING_R_torsionspring_UNVERIFIED
ROLLER_SHAFT_REX_UNVERIFIED
STAR_SHAFT_REX_UNVERIFIED
JACK_SHAFT_REX_UNVERIFIED
ROLLER_LOW_ribbed_UNVERIFIED
ROLLER_TOP_starroller_asm_VENDOR-PENDING
INT_BRG_L_flg8mm_UNVERIFIED
INT_BRG_R_flg8mm_UNVERIFIED
PIVOT_PIN_L_O8_UNVERIFIED
PIVOT_PIN_R_O8_UNVERIFIED
INT_MOTOR_5203compact_VENDOR-PENDING
SPROCKET_9T_25chain_VENDOR-PENDING
SPROCKET_16T_25chain_VENDOR-PENDING
CHAIN_25_rollerchain_VENDOR-PENDING
MASTER_LINK_cliplink_VENDOR-PENDING
CHAIN_GUARD_2mm_UNVERIFIED
BELT_PUL_LOW_HTD_UNVERIFIED
BELT_PUL_TOP_HTD_UNVERIFIED
BELT_XROLL_crossedHTD_UNVERIFIED
TENS_ARM_pivot_UNVERIFIED
TENS_POST_pivot_UNVERIFIED
TENS_IDLER_O30_UNVERIFIED
TENS_PIN_O8_UNVERIFIED
TENS_SPRING_torsionspring_UNVERIFIED
THROAT_GUARD_2mm_UNVERIFIED
MOUNT_PLATE_L_motorplate_UNVERIFIED
MOUNT_PLATE_R_motorplate_UNVERIFIED
FRAME_RAIL_L_gobilda1120_invU_444.5_VENDOR-PENDING
FRAME_RAIL_R_gobilda1120_invU_444.5_VENDOR-PENDING
FRAME_CROSS_B_invU_271.8_VENDOR-PENDING
FRAME_CROWN_F_invU_271.8_raised_VENDOR-PENDING
CROWN_POST_L_post_UNVERIFIED
GUSSET_BL_Lgusset_40x40_UNVERIFIED
GUSSET_UL_Lgusset_low_UNVERIFIED
TIE_RB_L_splice_30x72x3_UNVERIFIED
CROWN_POST_R_post_UNVERIFIED
GUSSET_BR_Lgusset_40x40_UNVERIFIED
GUSSET_UR_Lgusset_low_UNVERIFIED
TIE_RB_R_splice_30x72x3_UNVERIFIED
BELLY_PAN_sheet_UNVERIFIED
PAN_BRKT_L0_Lbracket_UNVERIFIED
PAN_BRKT_L1_Lbracket_UNVERIFIED
PAN_BRKT_L2_Lbracket_UNVERIFIED
PAN_BRKT_R0_Lbracket_UNVERIFIED
PAN_BRKT_R1_Lbracket_UNVERIFIED
PAN_BRKT_R2_Lbracket_UNVERIFIED
DECK_L_deck_panel_UNVERIFIED
DECK_POST_L0_hexstandoff_O10_UNVERIFIED
DECK_POST_L1_hexstandoff_O10_UNVERIFIED
DECK_POST_L2_hexstandoff_O10_UNVERIFIED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

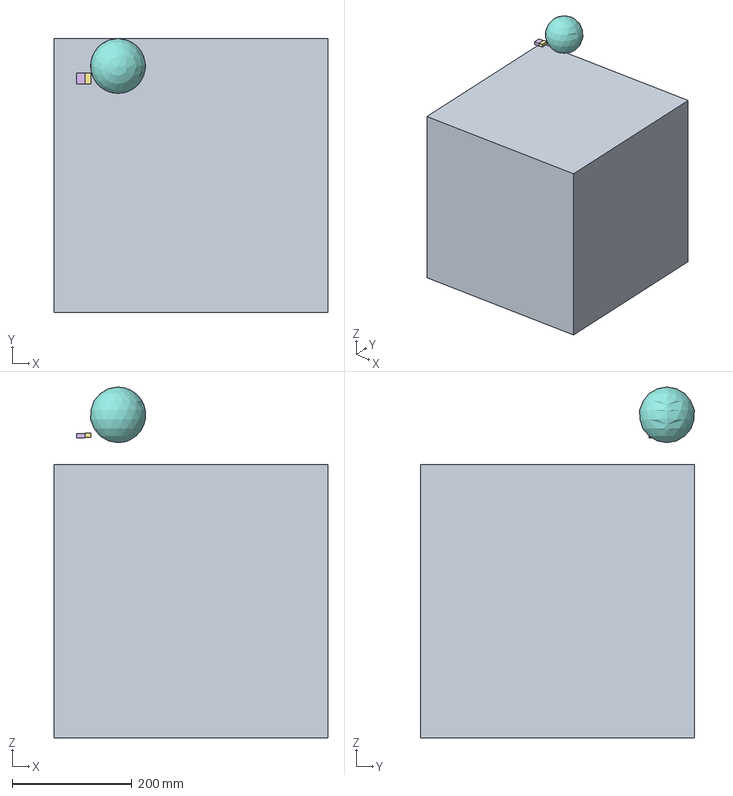
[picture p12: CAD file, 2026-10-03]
cad/lift/lift.FCStd
457.2 x 457.4 x 586.5 mm
ENV_START_457.2cube_VERIFIED
MOUNT_PLATE_L_motorplate_UNVERIFIED
MOUNT_PLATE_R_motorplate_UNVERIFIED
FRAME_RAIL_L_gobilda1120_invU_444.5_VENDOR-PENDING
FRAME_RAIL_R_gobilda1120_invU_444.5_VENDOR-PENDING
FRAME_CROSS_B_invU_271.8_VENDOR-PENDING
FRAME_CROWN_F_invU_271.8_raised_VENDOR-PENDING
CROWN_POST_L_post_UNVERIFIED
GUSSET_BL_Lgusset_40x40_UNVERIFIED
GUSSET_UL_Lgusset_low_UNVERIFIED
TIE_RB_L_splice_30x72x3_UNVERIFIED
CROWN_POST_R_post_UNVERIFIED
GUSSET_BR_Lgusset_40x40_UNVERIFIED
GUSSET_UR_Lgusset_low_UNVERIFIED
TIE_RB_R_splice_30x72x3_UNVERIFIED
BELLY_PAN_sheet_UNVERIFIED
PAN_BRKT_L0_Lbracket_UNVERIFIED
PAN_BRKT_L1_Lbracket_UNVERIFIED
PAN_BRKT_L2_Lbracket_UNVERIFIED
PAN_BRKT_R0_Lbracket_UNVERIFIED
PAN_BRKT_R1_Lbracket_UNVERIFIED
PAN_BRKT_R2_Lbracket_UNVERIFIED
DECK_L_deck_panel_UNVERIFIED
DECK_POST_L0_hexstandoff_O10_UNVERIFIED
DECK_POST_L1_hexstandoff_O10_UNVERIFIED
DECK_POST_L2_hexstandoff_O10_UNVERIFIED
DECK_POST_L3_hexstandoff_O10_UNVERIFIED
DECK_R_deck_panel_UNVERIFIED
DECK_POST_R0_hexstandoff_O10_UNVERIFIED
DECK_POST_R1_hexstandoff_O10_UNVERIFIED
DECK_POST_R2_hexstandoff_O10_UNVERIFIED
DECK_POST_R3_hexstandoff_O10_UNVERIFIED
ENDCAP_FL_endplug_UNVERIFIED
ENDCAP_BL_endplug_UNVERIFIED
ENDCAP_FR_endplug_UNVERIFIED
ENDCAP_BR_endplug_UNVERIFIED
ENDCAP_XB_L_endplug_UNVERIFIED
ENDCAP_XB_R_endplug_UNVERIFIED
PLATE_NUM_L_alliance_plate_UNVERIFIED
PLATE_NUM_B_alliance_plate_UNVERIFIED
LIFT_BASE_3mm_alu_UNVERIFIED
LIFT_RAIL_L_14x14_UNVERIFIED
LIFT_FOOT_L_UNVERIFIED
LIFT_RAIL_R_14x14_UNVERIFIED
LIFT_FOOT_R_UNVERIFIED
LIFT_TOP_TIE_UNVERIFIED
LIFT_TPIN_O6_UNVERIFIED
LIFT_TOP_PULLEY_O20_UNVERIFIED
ROPE_GUIDE_eyelet_UNVERIFIED
STOP_COLLAR_L_UNVERIFIED
STOP_COLLAR_R_UNVERIFIED
LIFT_S1_TRUCK_L0_delrin_UNVERIFIED
LIFT_S1_TRUCK_L1_delrin_UNVERIFIED
LIFT_S1_BAR_L_slide_UNVERIFIED
LIFT_S1_TRUCK_R0_delrin_UNVERIFIED
LIFT_S1_TRUCK_R1_delrin_UNVERIFIED
LIFT_S1_BAR_R_slide_UNVERIFIED
LIFT_S1_TIE_UNVERIFIED
S1_PPIN_O6_UNVERIFIED
LIFT_PULLEY_O20_UNVERIFIED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

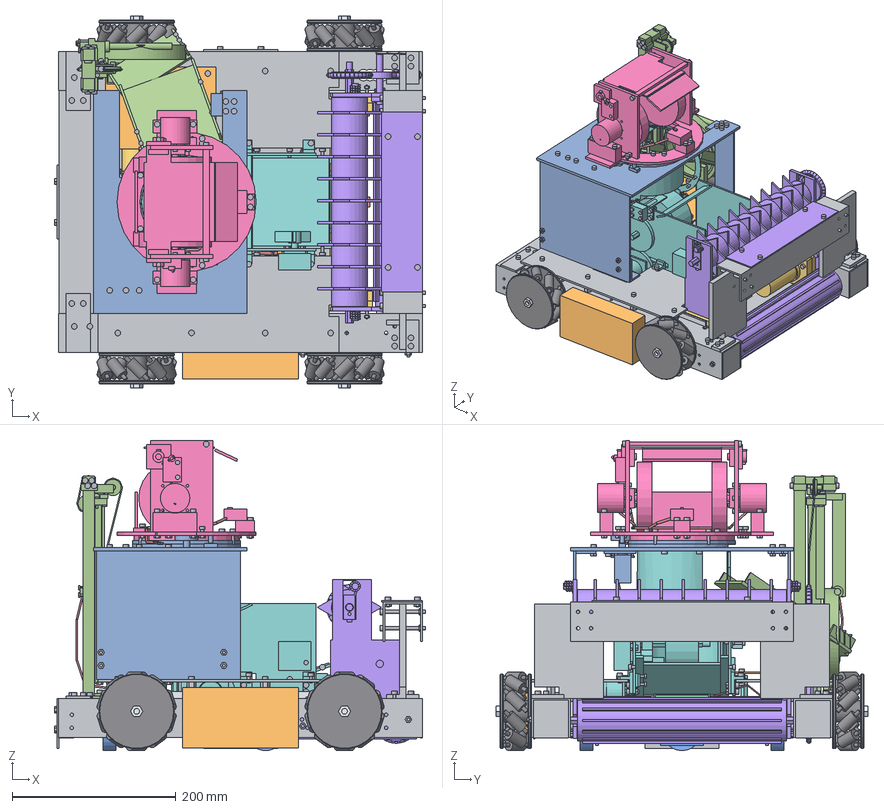
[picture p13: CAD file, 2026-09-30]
cad/master_robot_view.FCStd
453.7 x 454.5 x 379.0 mm
INT_CHEEK_L_5mmPETG_UNVERIFIED
FLOAT_SLIDE_L_acetal_UNVERIFIED
FLOAT_PIN_L_O4_UNVERIFIED
SPRING_POST_L_O8_UNVERIFIED
TORSION_SPRING_L_torsionspring_UNVERIFIED
INT_CHEEK_R_5mmPETG_UNVERIFIED
FLOAT_SLIDE_R_acetal_UNVERIFIED
FLOAT_PIN_R_O4_UNVERIFIED
SPRING_POST_R_O8_UNVERIFIED
TORSION_SPRING_R_torsionspring_UNVERIFIED
ROLLER_SHAFT_REX_UNVERIFIED
STAR_SHAFT_REX_UNVERIFIED
JACK_SHAFT_REX_UNVERIFIED
ROLLER_LOW_ribbed_UNVERIFIED
ROLLER_TOP_starroller_asm_VENDOR-PENDING
INT_BRG_L_flg8mm_UNVERIFIED
INT_BRG_R_flg8mm_UNVERIFIED
PIVOT_PIN_L_O8_UNVERIFIED
PIVOT_PIN_R_O8_UNVERIFIED
INT_MOTOR_5203compact_VENDOR-PENDING
SPROCKET_9T_25chain_VENDOR-PENDING
SPROCKET_16T_25chain_VENDOR-PENDING
CHAIN_25_rollerchain_VENDOR-PENDING
MASTER_LINK_cliplink_VENDOR-PENDING
CHAIN_GUARD_2mm_UNVERIFIED
BELT_PUL_LOW_HTD_UNVERIFIED
BELT_PUL_TOP_HTD_UNVERIFIED
BELT_XROLL_crossedHTD_UNVERIFIED
TENS_ARM_pivot_UNVERIFIED
TENS_POST_pivot_UNVERIFIED
TENS_IDLER_O30_UNVERIFIED
TENS_PIN_O8_UNVERIFIED
TENS_SPRING_torsionspring_UNVERIFIED
THROAT_GUARD_2mm_UNVERIFIED
MOUNT_PLATE_L_motorplate_UNVERIFIED
MOUNT_PLATE_R_motorplate_UNVERIFIED
WHEEL_HUB_FL_O26_hexbore_VENDOR-PENDING
WHEEL_PLATE_FL_IN_O92_VENDOR-PENDING
WHEEL_PLATE_FL_OUT_O92_VENDOR-PENDING
ROLLER_FL_00_B_O14_roller_axle_pin_VENDOR-PENDING
ROLLER_FL_01_B_O14_roller_axle_pin_VENDOR-PENDING
ROLLER_FL_02_B_O14_roller_axle_pin_VENDOR-PENDING
ROLLER_FL_03_B_O14_roller_axle_pin_VENDOR-PENDING
ROLLER_FL_04_B_O14_roller_axle_pin_VENDOR-PENDING
ROLLER_FL_05_B_O14_roller_axle_pin_VENDOR-PENDING
ROLLER_FL_06_B_O14_roller_axle_pin_VENDOR-PENDING
ROLLER_FL_07_B_O14_roller_axle_pin_VENDOR-PENDING
ROLLER_FL_08_B_O14_roller_axle_pin_VENDOR-PENDING
ROLLER_FL_09_B_O14_roller_axle_pin_VENDOR-PENDING
BOLT_HUB_FL_M4_pinch_UNVERIFIED
AXLE_FL_8mmREX_M8tip_VENDOR-PENDING
BRG_IN_FL_flangeblock_26x6_VENDOR-PENDING
BRG_OUT_FL_flangeblock_26x6_VENDOR-PENDING
MOTOR_FL_5203class_gb_VENDOR-PENDING
WSH_AXLE_FL_O16_UNVERIFIED
COLLAR_FL_O18_UNVERIFIED
PINION_FL_15T_hub_UNVERIFIED
NUT_AXLE_FL_M8nylock_UNVERIFIED
CLAMP_FL_2_splitring_UNVERIFIED
CLAMP_FL_1_splitring_UNVERIFIED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

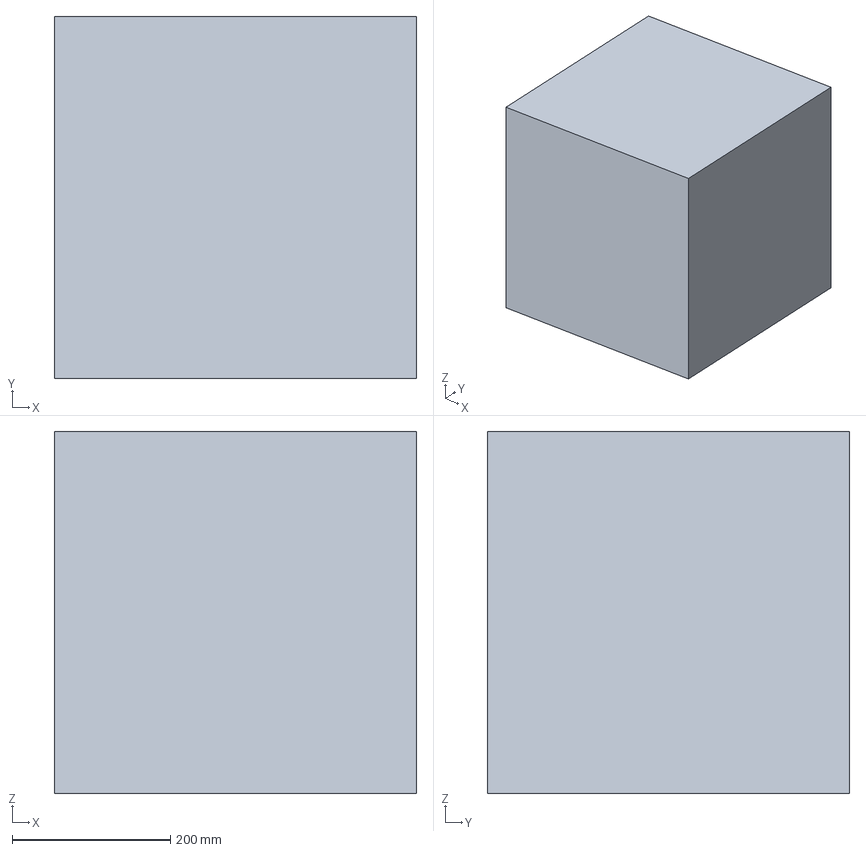
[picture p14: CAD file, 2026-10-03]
cad/turret/turret.FCStd
457.2 x 457.2 x 457.2 mm
ENV_START_457.2cube_VERIFIED
MOUNT_PLATE_L_motorplate_UNVERIFIED
MOUNT_PLATE_R_motorplate_UNVERIFIED
FRAME_RAIL_L_gobilda1120_invU_444.5_VENDOR-PENDING
FRAME_RAIL_R_gobilda1120_invU_444.5_VENDOR-PENDING
FRAME_CROSS_B_invU_271.8_VENDOR-PENDING
FRAME_CROWN_F_invU_271.8_raised_VENDOR-PENDING
CROWN_POST_L_post_UNVERIFIED
GUSSET_BL_Lgusset_40x40_UNVERIFIED
GUSSET_UL_Lgusset_low_UNVERIFIED
TIE_RB_L_splice_30x72x3_UNVERIFIED
CROWN_POST_R_post_UNVERIFIED
GUSSET_BR_Lgusset_40x40_UNVERIFIED
GUSSET_UR_Lgusset_low_UNVERIFIED
TIE_RB_R_splice_30x72x3_UNVERIFIED
BELLY_PAN_sheet_UNVERIFIED
PAN_BRKT_L0_Lbracket_UNVERIFIED
PAN_BRKT_L1_Lbracket_UNVERIFIED
PAN_BRKT_L2_Lbracket_UNVERIFIED
PAN_BRKT_R0_Lbracket_UNVERIFIED
PAN_BRKT_R1_Lbracket_UNVERIFIED
PAN_BRKT_R2_Lbracket_UNVERIFIED
DECK_L_deck_panel_UNVERIFIED
DECK_POST_L0_hexstandoff_O10_UNVERIFIED
DECK_POST_L1_hexstandoff_O10_UNVERIFIED
DECK_POST_L2_hexstandoff_O10_UNVERIFIED
DECK_POST_L3_hexstandoff_O10_UNVERIFIED
DECK_R_deck_panel_UNVERIFIED
DECK_POST_R0_hexstandoff_O10_UNVERIFIED
DECK_POST_R1_hexstandoff_O10_UNVERIFIED
DECK_POST_R2_hexstandoff_O10_UNVERIFIED
DECK_POST_R3_hexstandoff_O10_UNVERIFIED
ENDCAP_FL_endplug_UNVERIFIED
ENDCAP_BL_endplug_UNVERIFIED
ENDCAP_FR_endplug_UNVERIFIED
ENDCAP_BR_endplug_UNVERIFIED
ENDCAP_XB_L_endplug_UNVERIFIED
ENDCAP_XB_R_endplug_UNVERIFIED
PLATE_NUM_L_alliance_plate_UNVERIFIED
PLATE_NUM_B_alliance_plate_UNVERIFIED
TOWER_L_3mm_polycarb_UNVERIFIED
TOWER_R_3mm_polycarb_UNVERIFIED
TOWER_GUS_L0_3mm_alu_UNVERIFIED
TOWER_GUS_L1_3mm_alu_UNVERIFIED
TOWER_GUS_R2_3mm_alu_UNVERIFIED
TOWER_GUS_R3_3mm_alu_UNVERIFIED
TURRET_DECK_4mm_petg_UNVERIFIED
LAZY_SUSAN_LO_132x116_UNVERIFIED
LAZY_SUSAN_HI_132x116_UNVERIFIED
YAW_TRAY_3mm_steel_UNVERIFIED
YAW_SERVO_CRservo_UNVERIFIED
YAW_SHAFT_O8_UNVERIFIED
YAW_PINION_14T_PD23.7_UNVERIFIED
HALL_SNSR_reed_UNVERIFIED
RING_GEAR_72T_PD121.9_UNVERIFIED
TURRET_PLATE_4mm_acetal_UNVERIFIED
LAUNCH_CHEEK_L_5mm_petg_UNVERIFIED
LAUNCH_CHEEK_R_5mm_petg_UNVERIFIED
FLYWHEEL_L_O88.9_VENDOR-PENDING
FLY_CLAMP_L_O17.8_UNVERIFIED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

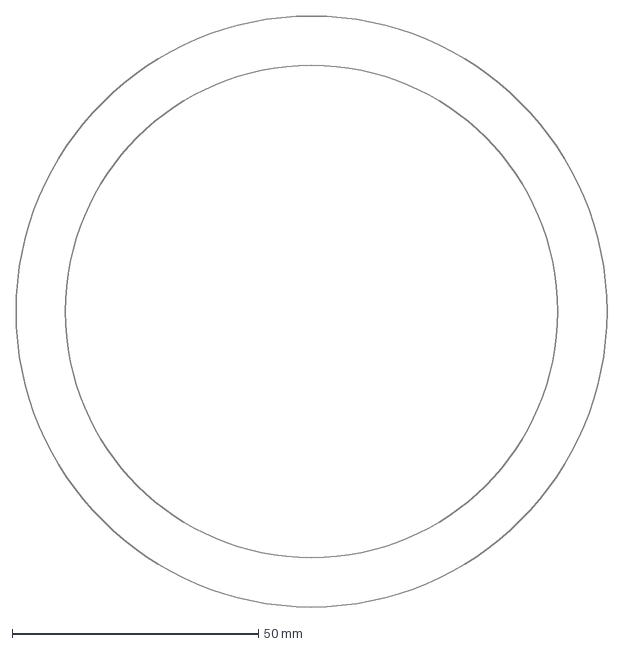
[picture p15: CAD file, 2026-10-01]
exports/drawings/sample/dxf/hopper_PORT_FLANGE.dxf
120.0 x 120.0 mm

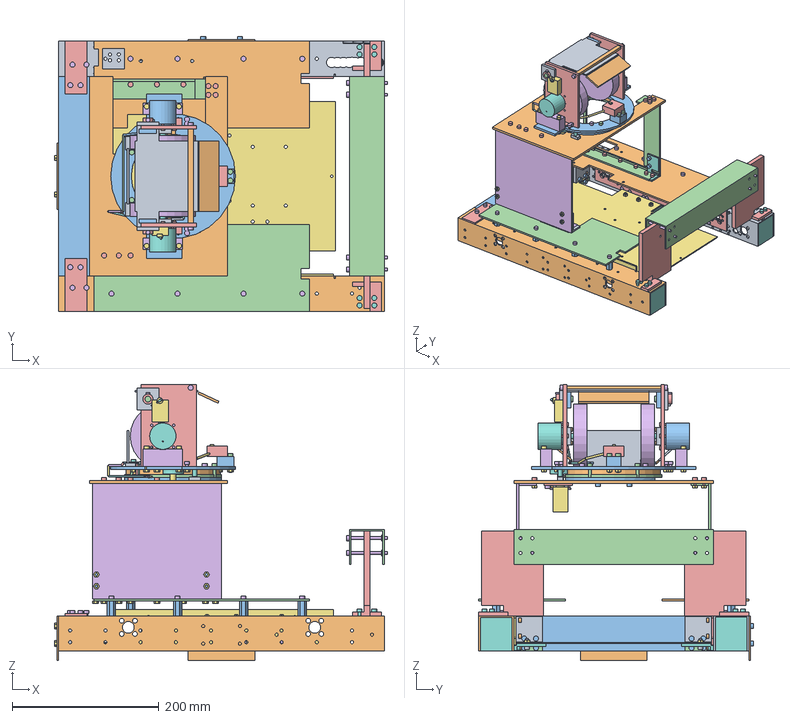
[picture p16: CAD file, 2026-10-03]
exports/step/subassembly/turret.step
453.7 x 374.0 x 376.2 mm
FRAME_RAIL_L
FRAME_RAIL_R
FRAME_CROSS_B
FRAME_CROWN_F
CROWN_POST_L
BOLT_CROWN_L_0
NUT_CROWN_L_0
BOLT_CROWN_L_1
NUT_CROWN_L_1
BOLT_CPOSTF_L_0
NUT_CPOSTF_L_0
BOLT_CPOSTF_L_1
NUT_CPOSTF_L_1
BOLT_CPOSTF_L_2
NUT_CPOSTF_L_2
BOLT_CPOSTF_L_3
NUT_CPOSTF_L_3
GUSSET_BL
BOLT_GUS_L_0_0
NUT_GUS_L_0_0
BOLT_GUS_L_0_1
NUT_GUS_L_0_1
BOLT_GUS_L_1_0
NUT_GUS_L_1_0
BOLT_GUS_L_1_1
NUT_GUS_L_1_1
BOLT_GUSX_L_0
NUT_GUSX_L_0
BOLT_GUSX_L_1
NUT_GUSX_L_1
GUSSET_UL
BOLT_GUSU_L_0_0
NUT_GUSU_L_0_0
BOLT_GUSU_L_1_0
NUT_GUSU_L_1_0
BOLT_GUSU_XL_0
NUT_GUSU_XL_0
BOLT_GUSU_XL_1
NUT_GUSU_XL_1
TIE_RB_L
BOLT_TIE_L_0
NUT_TIE_L_0
BOLT_TIE_L_1
NUT_TIE_L_1
BOLT_TIE_L_2
NUT_TIE_L_2
BOLT_TIE_L_3
NUT_TIE_L_3
CROWN_POST_R
BOLT_CROWN_R_0
NUT_CROWN_R_0
BOLT_CROWN_R_1
NUT_CROWN_R_1
BOLT_CPOSTF_R_0
NUT_CPOSTF_R_0
BOLT_CPOSTF_R_1
NUT_CPOSTF_R_1
BOLT_CPOSTF_R_2
NUT_CPOSTF_R_2
BOLT_CPOSTF_R_3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

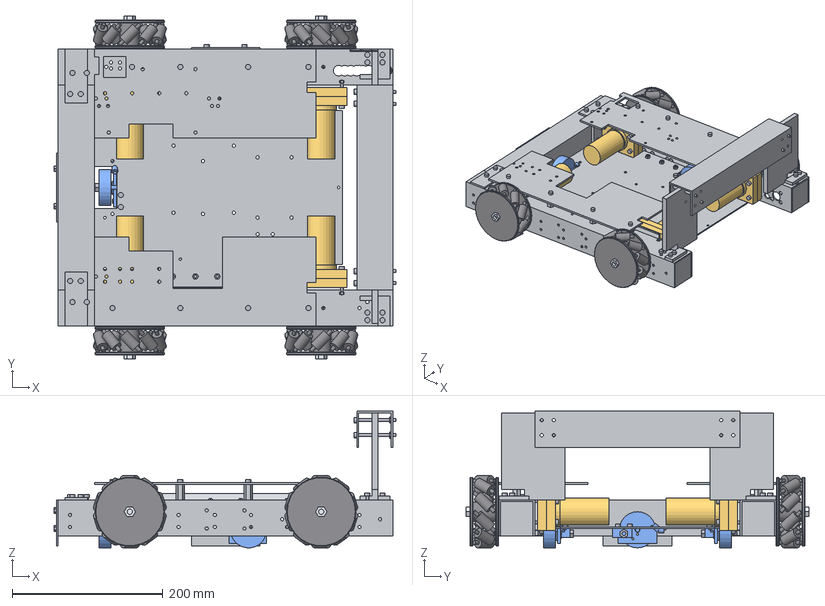
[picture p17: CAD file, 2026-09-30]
cad/drivebase/drivebase_view.FCStd
453.7 x 454.5 x 181.5 mm
MOUNT_PLATE_L_motorplate_UNVERIFIED
MOUNT_PLATE_R_motorplate_UNVERIFIED
WHEEL_HUB_FL_O26_hexbore_VENDOR-PENDING
WHEEL_PLATE_FL_IN_O92_VENDOR-PENDING
WHEEL_PLATE_FL_OUT_O92_VENDOR-PENDING
ROLLER_FL_00_B_O14_roller_axle_pin_VENDOR-PENDING
ROLLER_FL_01_B_O14_roller_axle_pin_VENDOR-PENDING
ROLLER_FL_02_B_O14_roller_axle_pin_VENDOR-PENDING
ROLLER_FL_03_B_O14_roller_axle_pin_VENDOR-PENDING
ROLLER_FL_04_B_O14_roller_axle_pin_VENDOR-PENDING
ROLLER_FL_05_B_O14_roller_axle_pin_VENDOR-PENDING
ROLLER_FL_06_B_O14_roller_axle_pin_VENDOR-PENDING
ROLLER_FL_07_B_O14_roller_axle_pin_VENDOR-PENDING
ROLLER_FL_08_B_O14_roller_axle_pin_VENDOR-PENDING
ROLLER_FL_09_B_O14_roller_axle_pin_VENDOR-PENDING
BOLT_HUB_FL_M4_pinch_UNVERIFIED
AXLE_FL_8mmREX_M8tip_VENDOR-PENDING
BRG_IN_FL_flangeblock_26x6_VENDOR-PENDING
BRG_OUT_FL_flangeblock_26x6_VENDOR-PENDING
MOTOR_FL_5203class_gb_VENDOR-PENDING
WSH_AXLE_FL_O16_UNVERIFIED
COLLAR_FL_O18_UNVERIFIED
PINION_FL_15T_hub_UNVERIFIED
NUT_AXLE_FL_M8nylock_UNVERIFIED
CLAMP_FL_2_splitring_UNVERIFIED
CLAMP_FL_1_splitring_UNVERIFIED
WHEEL_HUB_FR_O26_hexbore_VENDOR-PENDING
WHEEL_PLATE_FR_IN_O92_VENDOR-PENDING
WHEEL_PLATE_FR_OUT_O92_VENDOR-PENDING
ROLLER_FR_00_B_O14_roller_axle_pin_VENDOR-PENDING
ROLLER_FR_01_B_O14_roller_axle_pin_VENDOR-PENDING
ROLLER_FR_02_B_O14_roller_axle_pin_VENDOR-PENDING
ROLLER_FR_03_B_O14_roller_axle_pin_VENDOR-PENDING
ROLLER_FR_04_B_O14_roller_axle_pin_VENDOR-PENDING
ROLLER_FR_05_B_O14_roller_axle_pin_VENDOR-PENDING
ROLLER_FR_06_B_O14_roller_axle_pin_VENDOR-PENDING
ROLLER_FR_07_B_O14_roller_axle_pin_VENDOR-PENDING
ROLLER_FR_08_B_O14_roller_axle_pin_VENDOR-PENDING
ROLLER_FR_09_B_O14_roller_axle_pin_VENDOR-PENDING
BOLT_HUB_FR_M4_pinch_UNVERIFIED
AXLE_FR_8mmREX_M8tip_VENDOR-PENDING
BRG_IN_FR_flangeblock_26x6_VENDOR-PENDING
BRG_OUT_FR_flangeblock_26x6_VENDOR-PENDING
MOTOR_FR_5203class_gb_VENDOR-PENDING
WSH_AXLE_FR_O16_UNVERIFIED
COLLAR_FR_O18_UNVERIFIED
PINION_FR_15T_hub_UNVERIFIED
NUT_AXLE_FR_M8nylock_UNVERIFIED
CLAMP_FR_2_splitring_UNVERIFIED
CLAMP_FR_1_splitring_UNVERIFIED
WHEEL_HUB_RL_O26_hexbore_VENDOR-PENDING
WHEEL_PLATE_RL_IN_O92_VENDOR-PENDING
WHEEL_PLATE_RL_OUT_O92_VENDOR-PENDING
ROLLER_RL_00_B_O14_roller_axle_pin_VENDOR-PENDING
ROLLER_RL_01_B_O14_roller_axle_pin_VENDOR-PENDING
ROLLER_RL_02_B_O14_roller_axle_pin_VENDOR-PENDING
ROLLER_RL_03_B_O14_roller_axle_pin_VENDOR-PENDING
ROLLER_RL_04_B_O14_roller_axle_pin_VENDOR-PENDING
ROLLER_RL_05_B_O14_roller_axle_pin_VENDOR-PENDING
ROLLER_RL_06_B_O14_roller_axle_pin_VENDOR-PENDING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

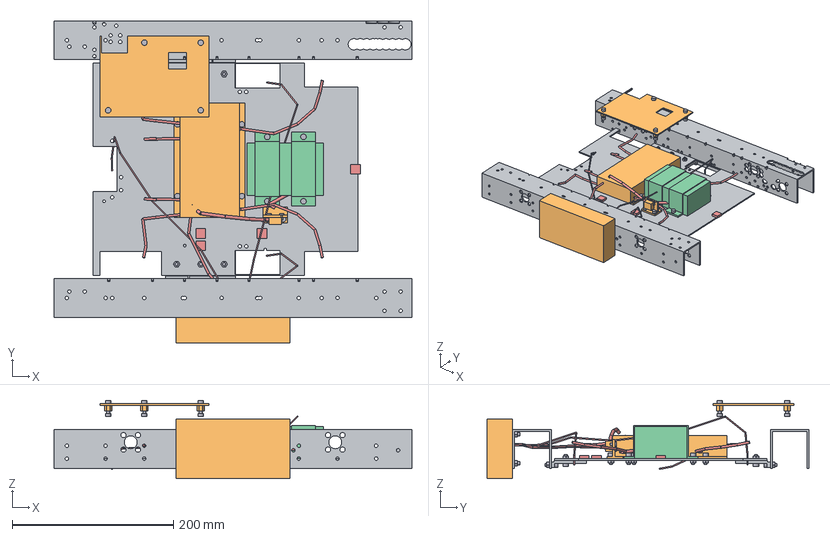
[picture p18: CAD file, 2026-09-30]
cad/electronics/electronics_view.FCStd
444.5 x 400.0 x 97.0 mm
FRAME_RAIL_L_gobilda1120_invU_444.5_VENDOR-PENDING
FRAME_RAIL_R_gobilda1120_invU_444.5_VENDOR-PENDING
BELLY_PAN_sheet_UNVERIFIED
PAN_BRKT_L0_Lbracket_UNVERIFIED
PAN_BRKT_L1_Lbracket_UNVERIFIED
PAN_BRKT_L2_Lbracket_UNVERIFIED
PAN_BRKT_R0_Lbracket_UNVERIFIED
PAN_BRKT_R1_Lbracket_UNVERIFIED
PAN_BRKT_R2_Lbracket_UNVERIFIED
BATTERY_3000mAh_pack_VENDOR-PENDING
BATT_STRAP_0_strap_UNVERIFIED
BATT_STRAP_1_strap_UNVERIFIED
ELEC_SHELF_tray_UNVERIFIED
STANDOFF_0_standoff_UNVERIFIED
STANDOFF_1_standoff_UNVERIFIED
STANDOFF_2_standoff_UNVERIFIED
STANDOFF_3_standoff_UNVERIFIED
SWITCH_BRKT_Lbracket_UNVERIFIED
MAIN_SWITCH_toggle_UNVERIFIED
SCRW_SW_0_M3_selftap_UNVERIFIED
SCRW_SW_1_M3_selftap_UNVERIFIED
HUB_CTRL_hubfeet_VENDOR-PENDING
HUB_EXP_railmount_VENDOR-PENDING
WIRE_BATT_SW_wirerun_UNVERIFIED
WIRE_SW_CTRL_wirerun_UNVERIFIED
WIRE_HUB_RS485_wirerun_UNVERIFIED
WIRE_MTR_FL_wirerun_UNVERIFIED
WIRE_MTR_RL_wirerun_UNVERIFIED
WIRE_MTR_FR_wirerun_UNVERIFIED
WIRE_MTR_RR_wirerun_UNVERIFIED
WIRE_ENC_LAT_L_wirerun_UNVERIFIED
WIRE_ENC_LAT_R_wirerun_UNVERIFIED
WIRE_ENC_LON_wirerun_UNVERIFIED
CLIP_0_cableclip_UNVERIFIED
CLIP_1_cableclip_UNVERIFIED
CLIP_2_cableclip_UNVERIFIED
CLIP_3_cableclip_UNVERIFIED
BOLT_PANB_L0_0_M4_UNVERIFIED
NUT_PANB_L0_0_M4_UNVERIFIED
BOLT_PANB_L0_1_M4_UNVERIFIED
NUT_PANB_L0_1_M4_UNVERIFIED
BOLT_PANF_L0_M4_UNVERIFIED
NUT_PANF_L0_M4_UNVERIFIED
BOLT_PANB_L1_0_M4_UNVERIFIED
NUT_PANB_L1_0_M4_UNVERIFIED
BOLT_PANB_L1_1_M4_UNVERIFIED
NUT_PANB_L1_1_M4_UNVERIFIED
BOLT_PANF_L1_M4_UNVERIFIED
NUT_PANF_L1_M4_UNVERIFIED
BOLT_PANB_L2_0_M4_UNVERIFIED
NUT_PANB_L2_0_M4_UNVERIFIED
BOLT_PANB_L2_1_M4_UNVERIFIED
NUT_PANB_L2_1_M4_UNVERIFIED
BOLT_PANF_L2_M4_UNVERIFIED
NUT_PANF_L2_M4_UNVERIFIED
BOLT_PANB_R0_0_M4_UNVERIFIED
NUT_PANB_R0_0_M4_UNVERIFIED
BOLT_PANB_R0_1_M4_UNVERIFIED
NUT_PANB_R0_1_M4_UNVERIFIED
BOLT_PANF_R0_M4_UNVERIFIED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

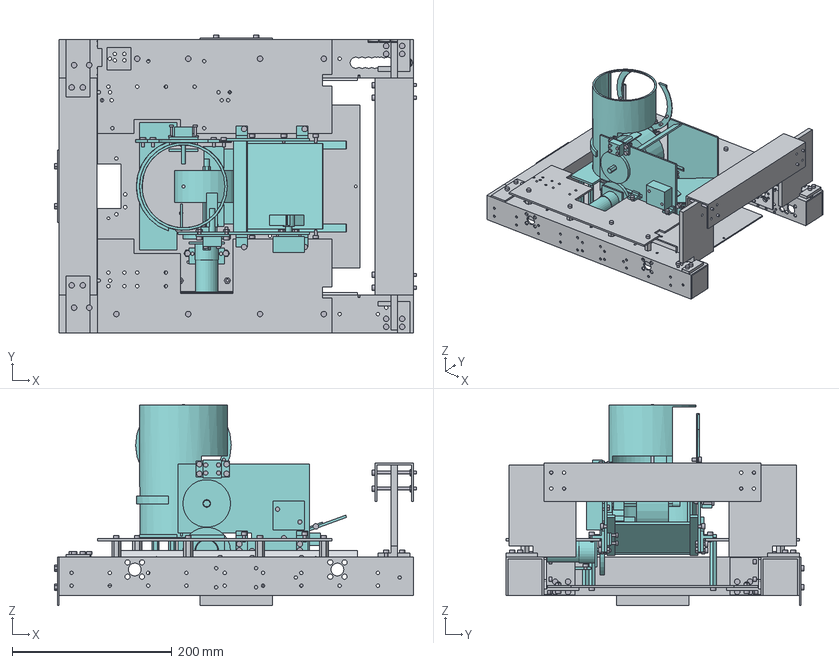
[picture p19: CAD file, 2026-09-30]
cad/hopper/hopper_view.FCStd
453.7 x 374.0 x 252.2 mm
MOUNT_PLATE_L_motorplate_UNVERIFIED
MOUNT_PLATE_R_motorplate_UNVERIFIED
FRAME_RAIL_L_gobilda1120_invU_444.5_VENDOR-PENDING
FRAME_RAIL_R_gobilda1120_invU_444.5_VENDOR-PENDING
FRAME_CROSS_B_invU_271.8_VENDOR-PENDING
FRAME_CROWN_F_invU_271.8_raised_VENDOR-PENDING
CROWN_POST_L_post_UNVERIFIED
GUSSET_BL_Lgusset_40x40_UNVERIFIED
GUSSET_UL_Lgusset_low_UNVERIFIED
TIE_RB_L_splice_30x72x3_UNVERIFIED
CROWN_POST_R_post_UNVERIFIED
GUSSET_BR_Lgusset_40x40_UNVERIFIED
GUSSET_UR_Lgusset_low_UNVERIFIED
TIE_RB_R_splice_30x72x3_UNVERIFIED
BELLY_PAN_sheet_UNVERIFIED
PAN_BRKT_L0_Lbracket_UNVERIFIED
PAN_BRKT_L1_Lbracket_UNVERIFIED
PAN_BRKT_L2_Lbracket_UNVERIFIED
PAN_BRKT_R0_Lbracket_UNVERIFIED
PAN_BRKT_R1_Lbracket_UNVERIFIED
PAN_BRKT_R2_Lbracket_UNVERIFIED
DECK_L_deck_panel_UNVERIFIED
DECK_POST_L0_hexstandoff_O10_UNVERIFIED
DECK_POST_L1_hexstandoff_O10_UNVERIFIED
DECK_POST_L2_hexstandoff_O10_UNVERIFIED
DECK_POST_L3_hexstandoff_O10_UNVERIFIED
DECK_R_deck_panel_UNVERIFIED
DECK_POST_R0_hexstandoff_O10_UNVERIFIED
DECK_POST_R1_hexstandoff_O10_UNVERIFIED
DECK_POST_R2_hexstandoff_O10_UNVERIFIED
DECK_POST_R3_hexstandoff_O10_UNVERIFIED
ENDCAP_FL_endplug_UNVERIFIED
ENDCAP_BL_endplug_UNVERIFIED
ENDCAP_FR_endplug_UNVERIFIED
ENDCAP_BR_endplug_UNVERIFIED
ENDCAP_XB_L_endplug_UNVERIFIED
ENDCAP_XB_R_endplug_UNVERIFIED
PLATE_NUM_L_alliance_plate_UNVERIFIED
PLATE_NUM_B_alliance_plate_UNVERIFIED
HOP_FLOOR_3mm_20deg_UNVERIFIED
HOP_APRON_3mm_UNVERIFIED
HOP_WALL_L_3mm_UNVERIFIED
HOP_WALL_R_3mm_UNVERIFIED
HOP_LEDGE_L_3mm_UNVERIFIED
HOP_LEDGE_R_3mm_UNVERIFIED
HOP_CURB_3mm_UNVERIFIED
HOP_BRKT_L_0_incorner_UNVERIFIED
HOP_BRKT_L_1_incorner_UNVERIFIED
HOP_BRKT_R_0_incorner_UNVERIFIED
HOP_BRKT_R_1_incorner_UNVERIFIED
AGIT_BRKT_alu_UNVERIFIED
AGIT_SERVO_servo_UNVERIFIED
AGIT_HORN_spline_UNVERIFIED
AGIT_PADDLE_3armPETG_UNVERIFIED
FEED_WHEEL_greencompliant_VENDOR-PENDING
FEED_SHAFT_REX_UNVERIFIED
FEED_WALL_BRG_flg8mm_UNVERIFIED
FEED_MOTOR_5203compact_VENDOR-PENDING
FEED_MTR_PLATE_alu_UNVERIFIED
FEED_STANDOFF_0_standoff_UNVERIFIED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

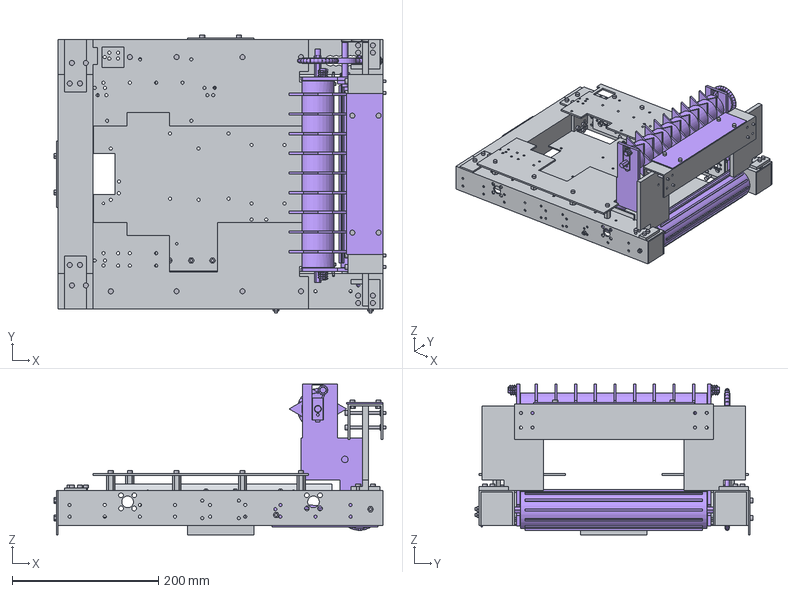
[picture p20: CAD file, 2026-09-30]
cad/intake/intake_view.FCStd
453.7 x 379.5 x 206.3 mm
INT_CHEEK_L_5mmPETG_UNVERIFIED
FLOAT_SLIDE_L_acetal_UNVERIFIED
FLOAT_PIN_L_O4_UNVERIFIED
SPRING_POST_L_O8_UNVERIFIED
TORSION_SPRING_L_torsionspring_UNVERIFIED
INT_CHEEK_R_5mmPETG_UNVERIFIED
FLOAT_SLIDE_R_acetal_UNVERIFIED
FLOAT_PIN_R_O4_UNVERIFIED
SPRING_POST_R_O8_UNVERIFIED
TORSION_SPRING_R_torsionspring_UNVERIFIED
ROLLER_SHAFT_REX_UNVERIFIED
STAR_SHAFT_REX_UNVERIFIED
JACK_SHAFT_REX_UNVERIFIED
ROLLER_LOW_ribbed_UNVERIFIED
ROLLER_TOP_starroller_asm_VENDOR-PENDING
INT_BRG_L_flg8mm_UNVERIFIED
INT_BRG_R_flg8mm_UNVERIFIED
PIVOT_PIN_L_O8_UNVERIFIED
PIVOT_PIN_R_O8_UNVERIFIED
INT_MOTOR_5203compact_VENDOR-PENDING
SPROCKET_9T_25chain_VENDOR-PENDING
SPROCKET_16T_25chain_VENDOR-PENDING
CHAIN_25_rollerchain_VENDOR-PENDING
MASTER_LINK_cliplink_VENDOR-PENDING
CHAIN_GUARD_2mm_UNVERIFIED
BELT_PUL_LOW_HTD_UNVERIFIED
BELT_PUL_TOP_HTD_UNVERIFIED
BELT_XROLL_crossedHTD_UNVERIFIED
TENS_ARM_pivot_UNVERIFIED
TENS_POST_pivot_UNVERIFIED
TENS_IDLER_O30_UNVERIFIED
TENS_PIN_O8_UNVERIFIED
TENS_SPRING_torsionspring_UNVERIFIED
THROAT_GUARD_2mm_UNVERIFIED
MOUNT_PLATE_L_motorplate_UNVERIFIED
MOUNT_PLATE_R_motorplate_UNVERIFIED
FRAME_RAIL_L_gobilda1120_invU_444.5_VENDOR-PENDING
FRAME_RAIL_R_gobilda1120_invU_444.5_VENDOR-PENDING
FRAME_CROSS_B_invU_271.8_VENDOR-PENDING
FRAME_CROWN_F_invU_271.8_raised_VENDOR-PENDING
CROWN_POST_L_post_UNVERIFIED
GUSSET_BL_Lgusset_40x40_UNVERIFIED
GUSSET_UL_Lgusset_low_UNVERIFIED
TIE_RB_L_splice_30x72x3_UNVERIFIED
CROWN_POST_R_post_UNVERIFIED
GUSSET_BR_Lgusset_40x40_UNVERIFIED
GUSSET_UR_Lgusset_low_UNVERIFIED
TIE_RB_R_splice_30x72x3_UNVERIFIED
BELLY_PAN_sheet_UNVERIFIED
PAN_BRKT_L0_Lbracket_UNVERIFIED
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

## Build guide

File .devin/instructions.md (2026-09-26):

# Agent instructions — BIOBUZZ-Robot

Guidance for anyone (human or agent) working in this repository.

## Building the CAD

FreeCAD headless binary (verified on this machine, v1.1.3):

```
C:\Program Files\FreeCAD 1.1\bin\freecadcmd.exe
```

Rebuild all sprint-01 models (idempotent — safe to re-run; all three
wrappers share `scripts\freecad\dt_build.py`):

```bat
"C:\Program Files\FreeCAD 1.1\bin\freecadcmd.exe" scripts\freecad\build_drivebase.py
"C:\Program Files\FreeCAD 1.1\bin\freecadcmd.exe" scripts\freecad\build_electronics.py
"C:\Program Files\FreeCAD 1.1\bin\freecadcmd.exe" scripts\freecad\build_master_robot.py
```

- `build_drivebase.py` → `cad\drivebase\drivebase.FCStd` (frame + drivetrain + pods)
- `build_electronics.py` → `cad\electronics\electronics.FCStd` (tray + wiring subset)
- `build_master_robot.py` → `cad\master_robot.FCStd` (sprint-01 union)

Each wrapper calls `dt_build.populate_*(doc, ctx)` then
`dt_build.finish_doc(...)` — recompute, shape validation, `GRP_*`
assembly grouping, save, and `exports\meta\<tag>.json` pair tables
(joints / faces / embeds / journals / contacts / ground census / bom).

Exports + previews + view state + gate (run after rebuilding):

```bat
"C:\Program Files\FreeCAD 1.1\bin\freecadcmd.exe" scripts\freecad\export_step.py
"C:\Program Files\FreeCAD 1.1\bin\freecadcmd.exe" scripts\freecad\make_view_copy.py
"C:\Program Files\FreeCAD 1.1\bin\freecadcmd.exe" scripts\freecad\render_png.py
"C:\Program Files\FreeCAD 1.1\bin\freecadcmd.exe" scripts\freecad\selfcheck_overhaul01.py
```

- `export_step.py` → `exports\step\parts\<name>.step` (per exportable
  solid), `exports\step\subassembly\GRP_*.step` + subsystem STEP,
  `exports\step\master_robot.step` (reimported + counted);
  `exports\bom\bom.csv`, `exports\parameters.csv`,
  `exports\mount_graph.json`
- `render_png.py` → `exports\renders\{master,drivebase,electronics}_{front,side,top,iso}.png`
  (shaded z-buffer raster; consumed/tool shapes excluded)
- `make_view_copy.py` → styled `*_view.FCStd` copies + in-place
  `GuiDocument.xml` injection (hides ENV_/TOOL_/consumed, subsystem
  palette, orthographic iso camera)
- `selfcheck_overhaul01.py` → the sprint-01 contract gate, 21 checks
  (GIT/DET/PAR/PROV/DAG/ASM/FAST/GEO/ENV/XPT/GUI), writes
  `exports\selfcheck_overhaul01.txt`; current result: **21/21 pass**
- `scripts\freecad\_probe_overlap.py` → standalone undeclared-overlap
  probe (same declared-pair table as the selfcheck)

## Conventions to keep

- All dimensions in mm; geometry stays parametric — bind dimensions to
  the `Parameters` spreadsheet via `setExpression`, never bake numbers
  into shape calls. Wire harness (`WIRE_*`) and baked strut segments are
  the sanctioned exception (baked endpoints).
- Coordinate convention in `docs\coordinate-system.md`: origin at center
  of the robot footprint on the tile surface; +X forward, +Y left, +Z up.
- Scripts resolve paths from `__file__` — never hardcode absolute paths
  (the repo may be checked out elsewhere, and evaluators mirror it).
- Every assumed dimension is `UNVERIFIED` — in `DataStatus` properties,
  in object labels (name carries a `_UNVERIFIED`/`_VENDOR-PENDING`
  suffix), and in `docs\robot-parameters.md`. `VERIFIED` requires a
  Competition Manual citation (R102, R105, §9.x, TU01). goBILDA-catalog
  values are `VENDOR-PENDING` until datasheets or physical parts confirm
  them — never VERIFIED.
- Every exportable solid carries a status token in its label, a
  `DataStatus` property, and membership in exactly one `GRP_*`
  `App::Part` (nested carriers like `WHEEL_ASSY_*` count through their
  parent chain).
- Construction intermediates live in `*_TOOLS` `Part::Compound`
  containers; consumed shapes (fuse/cut/chamfer inputs) are excluded
  from exports, probes, and renders. `exportable()`/`_consumed_add` in
  `selfcheck_overhaul01.py` is the reference implementation.
- Fastener model (R7 hybrid): real clearance bores through pass-through
  members; the bolt solid may embed only into the terminal threaded
  member (declared in `meta['embeds']`).
- Journal pairs (shaft↔bore) are declared in `meta['journals']`;
  mount face pairs in `meta['faces']`; incidental touch/contact pairs
  in `meta['contacts']`; spring/wire contacts in `meta['embeds']` or
  `contacts`. Anything that overlaps without a declaration fails GEO2.
- Children of `App::Part` carriers (e.g. `WHEEL_ASSY_*`) hold
  local-frame shapes — `o.Shape` ignores carrier placement. Use
  `o.Shape.copy(); s.Placement = o.getGlobalPlacement()` for analysis.
- The declared-overlap/contact tables emitted by `dt_build.py` are the
  contract — a newly discovered undeclared overlap is a failure to fix
  in geometry, not a reason to extend the declaration.
- If a build script would overwrite an FCStd containing foreign
  objects, archive a timestamped copy under `cad\archive\` first.

## Sprint-01 scope guard

The master intentionally contains sprint-01 solids only: frame,
drivetrain, three odometry pods, electronics tray, the sprint-01 wiring
subset, and all fasteners. Intake, hopper, turret, lift, servos,
camera, and USB-loom solids are sprint-02/03 scope — do not add them.

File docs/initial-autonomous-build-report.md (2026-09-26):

# Initial autonomous build report — BIOBUZZ-Robot sprint-01

## What was produced

Built by the autobuild Generator via `freecadcmd.exe` (FreeCAD 1.1.3):

- `cad\master_robot.FCStd` (≈14.7 KB, 31 objects / 14 solids) — packaging
  foundation: `Parameters` spreadsheet (19 bound aliases), R102 start
  envelope (457.2 mm cube, VERIFIED), R105 expansion envelope
  (457.2 × 609.6 × 736.5 mm, VERIFIED), 420 × 420 × 120 mm drivebase
  packaging volume, 4 wheel placeholders, battery and control-hub
  placeholders, and a `COORD_REF` coordinate-reference part with three
  axis-indicator solids at the world origin.
- `cad\drivebase\drivebase_concept_v01.FCStd` (≈9.4 KB, 19 objects /
  10 solids) — parametric chassis plate, 4 wheels, 4 motor placeholders, all
  bound to a 10-alias `Parameters` sheet.
- Build scripts: `scripts\freecad\build_master_robot.py`,
  `scripts\freecad\build_drivebase_concept.py`.
- Full documentation set under `docs\`.

## Project-root path note

The mission text referenced `C:\Users\pmsma\Documents\BIOBUZZ-Robot`; that
path does not exist on this machine. The real skeleton — and the root used
for all work — is `C:\Users\pmsma\OneDrive\Documents\BIOBUZZ-Robot`. The
scripts resolve paths from `__file__`, so they are unaffected by the
OneDrive location.

## How it was verified

- Both scripts executed via `freecadcmd.exe`: exit 0, `BUILD: DONE`.
- Each script run twice: identical sorted object lists, no duplicates, no
  archive or `.FCBak` strays under `cad\` (idempotent).
- Both FCStd reopened and recomputed cleanly; every solid `isValid()` with
  volume > 0; all expression bindings resolved (no `#ERR`).
- Mirror test: scripts copied to an empty `%TEMP%` tree recreate the FCStd
  files under the mirrored `cad\` — proving `__file__`-relative paths.
- Delta test on the drivebase: `chassis_length` +84 mm → chassis X extent
  +84 mm; `wheel_dia` +19.2 mm → wheel diameter extent +19.2 mm;
  `wheel_x_offset` +34 mm → wheel X placement +34 mm.

## Caveats (read before trusting the model)

- Every non-envelope dimension is an UNVERIFIED assumed placeholder — see
  `docs\robot-parameters.md` for status per parameter. Wheels, motors,
  battery, electronics, and chassis sizes have not been measured against
  real parts.
- Envelopes (R102/R105) are the only VERIFIED geometry, cited to the
  Competition Manual TU01.
- Intake, transfer, scoring, and endgame subsystems have no geometry —
  only reserved `cad\` folders and placeholder plans in
  `docs\mechanism-architecture.md`.
- This model asserts nothing about legality or fit; it is a packaging
  baseline for iteration.

---

## Sprint 02 append — mechanism concept placeholders (2026-09-20)

### What was added

- `cad\intake\intake_concept_v01.FCStd` (≈8 KB, 15 objects / 6 solids) —
  floor intake at the chassis front (+X): `THROAT_CLEAR` 120 × 110 mm
  opening (clears ~91 mm Nectar + margin), two floor-level rollers, frame
  and chassis-edge reference — all UNVERIFIED.
- `cad\transfer\transfer_concept_v01.FCStd` (≈8 KB, 15 objects / 6 solids) —
  `CHANNEL` clear 110 × 110 mm spanning 340 mm intake→scoring, wall guides,
  inlet/outlet zone markers — all UNVERIFIED.
- `cad\scoring\shooter_concept_v01.FCStd` (≈8 KB, 15 objects / 6 solids) —
  Pollen-primary housing, twin 72 mm flywheels (VENDOR-PENDING), 90 mm
  `MUZZLE_CLEAR`, `LAUNCH_DIR` +X indicator toward the Hive cell. Nectar
  capability is marked as an open question, not assumed.
- `cad\endgame\lifter_concept_v01.FCStd` (≈8.5 KB, 15 objects / 6 solids) —
  `LIFTER_STOWED` inside the R102 start cube (ZMin 120 mm, top-mounted),
  `LIFTER_DEPLOYED` mast ghost to 610 mm inside the R105 expansion volume,
  `CRADLE` 120 × 120 mm at ~570 mm — envelopes VERIFIED, lifter UNVERIFIED.
- `cad\master_robot.FCStd` extended (≈20.4 KB, 36 objects / 19 solids /
  39 aliases): `VOL_INTAKE`, `VOL_TRANSFER`, `VOL_SHOOTER`,
  `VOL_LIFTER_STOWED`, `VOL_LIFTER_DEPLOYED` packaging volumes; sprint-01
  objects unchanged; sprint-01 file preserved as
  `cad\archive\master_robot_sprint01_20260920_091818.FCStd`.
- `cad\drivebase\drivebase_concept_v01.FCStd`: wheel/motor placeholders
  relabeled goBILDA `UNVERIFIED - VENDOR-PENDING` with `VendorRef`;
  geometry unchanged.
- New scripts: `build_intake_concept.py`, `build_transfer_concept.py`,
  `build_shooter_concept.py`, `build_lifter_concept.py`; updated
  `build_master_robot.py`, `build_drivebase_concept.py`.

### How it was verified

- All six scripts run twice via `freecadcmd.exe`: exit 0, `BUILD: DONE`,
  identical object/alias sets, no stray files, no re-archiving.
- Reopen + `doc.recompute()` clean; all solids valid, volume > 0.
- Delta probes (±20 %) move bound geometry exactly: `throat_clear_w`
  +24 mm, `channel_w` +22 mm, `muzzle_clear` +18 mm, `reach_z` +122 mm;
  close-without-save leaves file hashes unchanged.
- Lifter checks: stowed bbox inside `ENV_START`, deployed bbox inside
  `ENV_EXPANSION` with ZMax 610 mm, stowed↔deployed CoG_xy offset 0 mm.
- Alias union across all six FCStd (70 names) is fully documented in
  `docs\robot-parameters.md`.

### Caveats (unchanged stance)

- Everything except the R102/R105 envelopes and the cited game-element
  facts remains UNVERIFIED or VENDOR-PENDING — packaging placeholders,
  not a design. Nectar-through-shooter was left undecided at sprint-02
  close; it is settled per D10 in sprint-03 (universal ~100 mm bore).

---

## Sprint 03 append — mechanism-level placeholders (2026-09-20)

### What was added

- `cad\drivebase\drivebase_concept_v01.FCStd` (21 objects / 12 solids):
  `RAIL_L`/`RAIL_R` goBILDA U-channel side rails 400 × 48 × 48 mm flush
  with the chassis sides (VENDOR-PENDING); 4 mecanum wheels + 4 motors
  unchanged (one per wheel, D9).
- `cad\intake\intake_concept_v01.FCStd` (19 objects / 10 solids): pivot
  side plates + rear `PIVOT_BOSS` hinge; `LIP_RAMP` tilted scoop lip at
  the mouth bottom (angle bound to `lip_ang`).
- `cad\transfer\transfer_concept_v01.FCStd` (19 objects / 10 solids):
  `DIVERTER_PADDLE` + `DIVERTER_AXIS` hinge at the scoring end;
  `ROUTE_POLLEN`/`ROUTE_NECTAR` markers for the Pollen→shooter /
  Nectar→hopper split.
- `cad\scoring\shooter_concept_v01.FCStd` (18 objects / 9 solids):
  universal ~100 mm `bore` between flywheel inner faces (D10 —
  Nectar-capable, settled), 110 mm `MUZZLE_CLEAR`, `HOOD` + `BACKSTOP` +
  `FEED_INLET`.
- `cad\endgame\lifter_concept_v01.FCStd` (20 objects / 11 solids): cascade
  elevator — nested `STAGE_1/2/3` inside the deployed ghost, `CARRIAGE`
  atop the inner stage, `CRADLE` riding at ~600 mm, `HARD_STOP` marker
  at the outer stage top (R105 physical-stop placeholder, UNVERIFIED).
- NEW `cad\electronics\electronics_concept_v01.FCStd` (14 objects /
  5 solids): `CHASSIS_VOL` reference + pairwise-disjoint `BATTERY`,
  `HUB_CTRL`, `HUB_EXP` REV-style placeholders (VENDOR-PENDING).
- `cad\master_robot.FCStd` untouched (36 objects, sprint-02 state);
  timestamped `*_sprint02_*` backups of all five upgraded targets staged
  in `cad\archive\` before reruns.

### How it was verified

- All six touched scripts run twice via `freecadcmd.exe`: exit 0,
  `BUILD: DONE`, identical object/alias sets, no strays, no re-archiving.
- Reopen + `doc.recompute()` clean; all solids valid, volume > 0.
- Delta probes move bound geometry exactly: `rail_w` +9.6 mm,
  `intake_width` +68 mm, `channel_w` +22 mm, `bore` +10 mm per flywheel
  face (+20 mm gap), `stage1_w` +15.2 mm, `battery_l` +36 mm;
  close-without-save leaves file hashes unchanged.
- Geometry floors: rail outer faces at chassis sides (|Y|=210);
  `LIP_RAMP` pitched 20° with `XMax ≥ THROAT_CLEAR.XMin`, `ZMin ≤ 30`;
  diverter hinge `XMin` within 80 mm of `CHANNEL.XMin`; bore gap = 100 mm
  = `bore`; cascade stages strictly nested ≥1 mm/face, union inside
  `LIFTER_DEPLOYED` +2 mm; hard-stop `ZMin ≥ STAGE_1.ZMax − 20`;
  electronics leaves disjoint ≤2 mm and inside `CHASSIS_VOL` +2 mm.
- Alias union across all seven FCStd (124 names) is fully documented in
  `docs\robot-parameters.md`; shooter Nectar strings carry no stale
  open/undecided qualifiers (D10 settled).

## Sprint 04 append — master integration + field references (2026-09-20)

### What changed

`cad\master_robot.FCStd` grew to 53 objects / 34 leaf solids. The flagged
sprint-02 reserve overlaps are resolved and each mechanism now places
representative `MECH_*` solids in the assembly:

- `intake_width` 340 -> 330 mm: `VOL_INTAKE` clears the wheel inner faces;
  `MECH_INTAKE_CHEEK_L/R` flank `MECH_ROLLER` inside the reserve.
- `channel_z` 100 -> 10 mm: the transfer lane is a floor-level
  through-chassis path (z 10..120), continuous with the intake throat;
  `VOL_TRANSFER`/`MECH_CHANNEL` end flush at the intake face via
  expression. `MECH_DIVERTER` marker sits face-adjacent at the -X end.
- `BATTERY` moved to the -Y chassis side, `ELECTRONICS` belly-mounted —
  placements expression-bound (`bat_*`, `elec_*`).
- Shooter reps: `MECH_SHOOTER_BODY` rear plate, `MECH_SHOOTER_HOOD`,
  `MECH_FLYWHEEL_L/R` at the 100 mm `bore` inner-face gap.
- Lifter reps: `MECH_LIFTER_STOWED`, telescoped `MECH_STAGE_1/2/3` inside
  `VOL_LIFTER_DEPLOYED`, `MECH_CARRIAGE`, `MECH_CRADLE` at ~600 mm.
- `REF_HIVE` aim marker ~800 mm past the front face at ~300 mm;
  `REF_FLOWER` at the 546 mm Flower top (§9.7 height VERIFIED, XY
  UNVERIFIED). Both labeled aiming references, never a field model.
- `intake_concept_v01` / `transfer_concept_v01` re-run with the shared
  `intake_width`/`channel_z` values — object sets unchanged.
- `docs\robot-parameters.md`: integration aliases documented + mass
  table (14.7 kg placeholder total — sum of subsystem rows, all
  UNVERIFIED).
- NEW `scripts\freecad\selfcheck_sprint04.py` — the contract gate.

### Declared co-locations (intended, not collisions)

Channel + intake inside the `VOL_DRIVEBASE` chassis bay; cascade stages
telescope (overlapping by design); the deployed ghost rises through the
stowed envelope's footprint; carriage/cradle may exceed the ghost at the
top; `ENV_*`/`AXIS_*`/`REF_*` and App::Part containers exempt from
overlap/envelope checks. Full leaf scan otherwise clean.

### How it was verified

- Timestamped `*_sprint03_20260920_120918.FCStd` backups staged for all
  three touched targets BEFORE the first upgraded run (pre-change param
  state: `intake_width`=340, `channel_z`=100, master = 36-object set).
- All three touched scripts run twice: exit 0, `BUILD: DONE`, identical
  object/alias sets, no strays; mirror-tree rebuilds from an unrelated
  cwd.
- `selfcheck_sprint04.py`: ALL PASS — C1-C4 named pairs disjoint, C6 full
  leaf scan clean, reps inside reserves +2 mm, bore gap = 100.0 mm,
  cradle ZMin = 600 >= 546, stowed solids inside R102 + deployed inside
  R105, REF_HIVE XMin 1028.6 / REF_FLOWER z-center 546.0, probes
  `intake_width` +66 mm and `reach_z` +122 mm exact, close-without-save
  hash stable.

## Sprint 05 append — prototype exports + renders (2026-09-20)

### What changed

NEW scripts (no model changes — all 8 FCStd byte-stable before/after):

- `scripts\freecad\export_prototypes.py` — exports the 21 robot leaf
  solids (4 wheels, `BATTERY`, `ELECTRONICS`, 15 `MECH_*`) from the master
  assembly; excludes `ENV_*`/`AXIS_*`/`REF_*` references, `VOL_*` reserves,
  and containers. Writes `exports\MANIFEST.md` + self-validation.
- `scripts\freecad\render_views.py` — headless orthographic SVG wireframe
  projections (front XZ / side YZ / top XY) via edge discretization — no
  GUI renderer exists in `freecadcmd`, so wireframe SVGs are the honest
  preview.

### Outputs

- `exports\prototype_stl\master_robot_PROTOTYPE.stl` — 3668 facets,
  bbox (-218, -192.5, 0)..(228.6, 192.5, 640) mm.
- `exports\prototype_step\master_robot_PROTOTYPE.step` — ISO-10303-21,
  re-import yields 22 solids (>=21 exported).
- `exports\renders\master_{front,side,top}.svg` — 189 polylines each,
  true-aspect views.
- `exports\MANIFEST.md` — object list, exclusion rule, and the
  PROTOTYPE / VERIFY BEFORE MANUFACTURING label per artifact.

### How it was verified

- Both scripts run twice via `freecadcmd.exe`: exit 0, idempotent
  overwrite, mirror-tree rebuilds from an unrelated cwd.
- STL re-parses via `Mesh.read` (facets > 0, bbox matches the exported
  set within 2 mm); STEP re-imports >= 21 solids.
- sha256 of all 7 live FCStd identical before and after the export/render
  runs — the scripts never mutate the models. (Earlier notes saying "8"
  were a miscount; the repository has 7 live FCStd files.)
- Exports and renders carry the PROTOTYPE / VERIFY BEFORE MANUFACTURING
  label in filenames and manifest; nothing here is manufacturing data.

## Sprint 06 append — detail + accuracy pass (2026-09-20)

### What changed

All 7 live FCStd rebuilt (pre-change archives under
`cad\archive\*_sprint05_20260920_135103.FCStd`). Still primitive,
expression-bound placeholder geometry — no manufacturing data.

- `build_drivebase_concept.py` / `build_master_robot.py`: 10 mecanum
  roller placeholders per wheel (`ROLLER_*_00..09`, Ø14 × 20 mm at ~45°
  slant, expression-bound `cos/sin(k * mec_roll_pitch)` positions, FTC
  X-pattern FL+RR vs FR+RL) + `ENV_WHEEL_*` envelope markers (Ø96 × 32 mm)
  + `MOUNT_MOTOR_*` plates (drivebase only).
- `build_intake_concept.py` / master: `PIVOT_MOUNT_L/R` cheek bosses;
  `intake_width` 330 → 326 mm (datasheet 32 mm wheels put inner faces at
  ±164 mm).
- `build_transfer_concept.py` / master: `DIVERTER_HORN` servo arm on the
  paddle.
- `build_shooter_concept.py` / master: `STUB_SHAFT_L/R` 8 mm REX shafts
  coaxial with the flywheels.
- `build_lifter_concept.py` / master: `STAGE_GUIDE_L/R` blocks riding the
  stage walls + `CRADLE_LIP` retention rim.
- `build_electronics_concept.py` / master: `ELEC_RAIL_L/R` hub rails.
- Datasheet corrections: `wheel_width` 25 → 32 mm, `motor_dia` 40 → 36 mm
  (goBILDA citations in `docs/robot-parameters.md`); mass-table basis now
  cites 207 g wheels / ~438 g motors — totals unchanged (2.6 / 14.7 kg).
- `export_prototypes.py`: export-set size now computed dynamically (the
  hardcoded 21 removed); manifest prints the computed count.
- `render_views.py`: colored per-subsystem fills (painter's algorithm) +
  wireframe overlay + legend; new `master_iso.svg` at orthographic
  az 45° / el 35.264°.
- New gate `selfcheck_sprint06.py` — supersedes the sprint-04 gate with
  the 9 enumerated overlap classes + roller asserts; probe values updated
  for `intake_width` 326.
- Encoding repair: this file had 17 stray cp1252 bytes (from an earlier
  PowerShell rewrite) — normalized to pure UTF-8.

### Outputs

- Master: 107 objects / 88 solids (71 exportable leaf solids).
- STL: 25740 facets, bbox (−218.0, −196.0, −0.0)–(228.6, 196.0, 640.0) —
  Y grew ±192.5 → ±196 with the cited 32 mm wheel width.
- STEP reimport: 72 solids (≥ 71 exported).
- SVGs: `master_{front,side,top,iso}.svg`, filled + wireframe, labeled
  PROTOTYPE / VERIFY BEFORE MANUFACTURING.

### How it was verified

- `selfcheck_sprint06.py`: 21/21 PASS — roller count/slant/X-pattern/
  envelope containment, leaf-scan under the declared exemption classes,
  R102/R105 containment, probes (intake_width 326→391.2, reach_z
  610→732), close-without-save hash stable.
- Export validation PASS; manifest lists the computed 71-object set.

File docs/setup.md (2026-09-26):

# Setup — BIOBUZZ-Robot

## Prerequisites

- FreeCAD 1.1 installed on Windows. The verified console binary is:
  `C:\Program Files\FreeCAD 1.1\bin\freecadcmd.exe` (v1.1.3, probe-verified).
- No other dependencies; the build scripts use only `FreeCAD`, `Part`, and
  `Spreadsheet` modules that ship with FreeCAD.

## Build the models

From `cmd.exe` or PowerShell (PowerShell needs the `&` call operator):

```bat
"C:\Program Files\FreeCAD 1.1\bin\freecadcmd.exe" scripts\freecad\build_master_robot.py
"C:\Program Files\FreeCAD 1.1\bin\freecadcmd.exe" scripts\freecad\build_drivebase_concept.py
```

```powershell
& "C:\Program Files\FreeCAD 1.1\bin\freecadcmd.exe" scripts\freecad\build_master_robot.py
& "C:\Program Files\FreeCAD 1.1\bin\freecadcmd.exe" scripts\freecad\build_drivebase_concept.py
```

Working directory does not matter — all scripts resolve the project root from
`__file__` (`<root>\scripts\freecad\` → `<root>`). The full build set (7
scripts) also covers `build_intake_concept.py`, `build_transfer_concept.py`,
`build_shooter_concept.py`, `build_lifter_concept.py`, and
`build_electronics_concept.py` — see `README.md` for the complete list.

Outputs:

- `cad\master_robot.FCStd` — robot packaging foundation (envelopes, drivebase
  volume, wheels, battery, electronics, mechanism `VOL_*` reserves +
  `MECH_*` representatives, `REF_*` aim markers, coordinate reference).
- `cad\*\*_concept_v01.FCStd` — one parametric concept per subsystem
  (drivebase, intake, transfer, scoring, endgame, electronics).

All files open in the FreeCAD GUI for inspection. Re-running a script
rebuilds the same object set (idempotent); if the target file ever contains
objects the script did not create, a timestamped copy is preserved under
`cad\archive\` first.

## Exports + previews

```bat
"C:\Program Files\FreeCAD 1.1\bin\freecadcmd.exe" scripts\freecad\export_prototypes.py
"C:\Program Files\FreeCAD 1.1\bin\freecadcmd.exe" scripts\freecad\render_views.py
```

Prototype STL/STEP land under `exports\prototype_stl` /
`exports\prototype_step`; colored SVG previews (front/side/top/iso) land
under `exports\renders`. All labeled `PROTOTYPE / VERIFY BEFORE
MANUFACTURING` — see `exports\MANIFEST.md`. The current geometry gate is
`scripts\freecad\selfcheck_sprint06.py` (writes
`selfcheck_sprint06_results.txt`).

## Optional smoke test

`scripts\validation\freecadcmd_probe.py` exercises the FreeCAD APIs the build
relies on:

```bat
"C:\Program Files\FreeCAD 1.1\bin\freecadcmd.exe" scripts\validation\freecadcmd_probe.py
```

Look for `PROBE: RESULT: PASS`.

## Editing parameters

Open either FCStd, edit the `Parameters` spreadsheet cells (column B), and
recompute — bound geometry follows. Canonical values/status are tracked in
`docs/robot-parameters.md`; axes follow `docs/coordinate-system.md`.

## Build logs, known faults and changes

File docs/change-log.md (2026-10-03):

# Change log - BIOBUZZ-Robot

## 2026-10-01 - Design finish: ball-path relief + repo cleanup + CAD-team README

Finish pass on `cloud/finish-design`, closing the open items from the
independent eval (`docs/eval-sprint03-independent.md`, merged as PR #4)
so the as-built model matches the verified ball corridor end to end.

- **Launch-corridor wiring** — `WIRE_FLY_L`'s mid-plane crossing
  rerouted: the old x -114 run sat ~1 mm inside the D93 sphere reach
  (<=151 mm3 graze on the S13->S14 corridor) and a naive x -120 push
  put it inside the nip-backplate wall. Final route swings out behind
  the backplate (x -134), drops outside the plate rim (x -154), rests
  on the rim top edge (keeps the declared wire-on-plate contact), and
  returns under-plate at z ~254; `WIRE_CAM_USB` waypoints moved
  outboard of the corridor and back inside the cheek-R face. Corridor
  sweep now reports zero sphere contacts and no undeclared overlaps.
- **Port-transition fasteners** — `CHUTE_PORT_EAR` + `BOLT_CHP_*`
  shifted 3.5 mm outboard and leg-1 lip screw stations re-spaced to
  clear both the S12->S15 transition and the S17 cradle-park sphere
  (`LIP_TS` leg-1 0.5/0.72 -> 0.35/0.45, leg-1R 0.3/0.7 -> 0.5/0.8).
  The straight S12->S15 transit now clears everything except a ~0.5 mm
  brush on the `PORT_FLANGE` sill edge, which is a designed ride
  surface (the ball exits over the sill).
- **Ride model documented** — `CHUTE_PTS + n*46.5` is the *ride*
  model: the ball enters leg-1 on a ballistic transition (the declared
  centerline's first ~10 points sit inside the lazy-susan/ring stack —
  a model artifact, since a physical sphere cannot occupy that space),
  rides the bed, and free-falls ~40 mm off the leg-2 tip into the
  cradle mouth. Densified sweep: launch corridor, bore descent, port
  exit, both ride legs, and the drop are clear; residual contacts are
  grazing brushes documented in the README (lip-tip screw, dyneema
  line, port sill).
- **Exports regenerated** — `export_step.py` and `make_drawings.py`
  re-run so the committed STEP parts, subassemblies, bom/meta, and the
  drawing manifest reflect the moved parts (580 sheets, 165 DXFs).
- **Repo cleanup** — removed ~100 build-lane scratch files from the
  repo root (`_probe_*.py`, `_verify*`, `_b_*.log`, gate-diff dumps,
  `_gold/` snapshots), the superseded `selfcheck_sprint0*_results.txt`
  transcripts, and tracked `logs/*.txt` (transient build logs; `logs/`
  now gitignored — matches the CI exclude convention). Stale
  `package.json` description updated.
- **README** — new "For the CAD team (SolidWorks)" section: STEP import
  guidance, drawings/DXF/BOM locations, the 245-UNVERIFIED /
  24-VENDOR-PENDING measurement checklist, and the documented
  ride-contact notes.

## 2026-10-01 - Sprint-04: viewer synced to as-built CAD, drawing pipeline + CI merged

Sprint-04 (`cloud/sprint-04`): the Three.js viewer now mirrors the built
CAD instead of the pre-overhaul sketch, the engineering-drawing pipeline
(PR #2) and the `cad-verify` GitHub Actions gate (PR #1) are merged, and
all three selfcheck suites stay green on this state (45/45, 61/61,
73/73 under FreeCAD 1.1.3).

- **Viewer as-built pass** — `viewer/js/robot.js` rewritten against the
  real FCStd geometry (world-bbox census of ~570 placed parts): external
  yaw ring mesh (72T ring on the turret outer rim, 14T pinion at 72.8 mm
  c.d., yaw servo at -Y of the turret axis), split lazy-susan races with
  the resolved z-stack (deck 244-248 / susan 248-256.5 / ring 256.5-263 /
  plate 263-267), two-leg LOAD_CHUTE (28.5deg + 21.8deg legs from the
  column port to the cradle), cradle bore Ø99 parked at z~140,
  electronics expansion hub on the right rail outer face, rail-mounted
  cross-drive belt intake, full fastener detail, windowed feed column
  (feed/gate/port cutouts), mast trucks/ties/feet/DPIN/rope guide, and
  corrected hopper incline/ledges/brackets. `main.js`/`demo.js`
  coordinates, labels, and anim paths resynced; deviations the viewer
  cannot express (e.g. modeled ring/sprocket tooth profiles) are noted
  in-code. Envelope still reads 17.5 x 17.5 x 14.9 in.
- **Drawing pipeline merged** (PR #2) — `drawing_kit.py` +
  `make_drawings.py` re-run on the final geometry: 574 unique parts ->
  574 dimensioned A4 sheets (PDF + SVG), 165 plate DXF profiles,
  manifest refreshed.
- **cad-verify workflow merged** (PR #1) — every push to main rebuilds
  all 7 docs + runs the three gate suites on a cached FreeCAD 1.1.3
  install; the check fails if any gate fails. CI-local commit excludes
  `logs/` and the selfcheck transcripts so `GIT2_tree_clean` measures a
  genuinely clean tree; `PYTHONUNBUFFERED` keeps the gate table in the
  console log (freecadcmd's exit path can drop buffered stdout).
- **Docs** — README quickstart/exports/layout refreshed (legacy
  `build_*_concept` scripts removed from the instructions),
  `exports/README.md` updated for as-built counts (1089 STEP parts,
  16 subassemblies, drawings dir).

Verification (`freecadcmd scripts/freecad/selfcheck_overhaul0N.py` on
this branch, FreeCAD 1.1.3): 45/45, 61/61, 73/73 PASS; viewer rendered
and inspected headless + live (iso/side presets); `cad-verify` check
green on the sprint-04 PR.

## 2026-09-30 - Overhaul sprint-03: turret + lift integrated assembly, 73/73 gates

Sprint-03 of the parametric overhaul (`autobuild/cad-overhaul`): full
physically-coherent turret, launcher, and two-stage flower lift on the
shared `partkit`/`Parameters` vocabulary, integrated into
`master_robot.FCStd` (1093 solids, 5035 objects).

- **Turret/launcher** - external yaw-ring mesh, literal deck/Susan/ring-
  gear/plate Z-stack, tower port + shelf window, launcher flywheels +
  hood, feed column, motor saddle, yaw tray - all expression-bound.
- **Flower lift** - two-stage mast with trucks/pads/ties, winch +
  Dyneema rope rig (baked two-run), cradle + tilt, and the LOAD_CHUTE
  two-leg tray (both legs >20deg slope, side lips, cradle-bowl dip).
- **Parametric propagation** - `tower_z1`, `plate_z`, `stop_z` are now
  derived formulas, so `turret_deck_z0` moves the whole turret stack
  (4/4 objects) and `lift_rail_len` moves rail + top tie + mast-top
  hardware. `ROPE_GUIDE` bound to `stop_z + 4`.
- **Declarations** - every intentional embed/contact/journal declared:
  165 fastener joints, 916 coplanar-face pairs, rope-wrap and
  wire-harness passes (`WIRE_*`/`ROPE_*` exempt from PAR3), truck/rail
  contacts, nut seats; stale `ROLLER_RL_*` bare-name refs removed.
- **Hub relocation** - `HUB_EXP` moved to the right frame rail outer
  face to clear the pinned S17 seat ball while still contacting
  `FRAME_RAIL_R`.
- **Exports** - 1089 part STEP files, 16 subassembly files,
  `master_robot.step` (reimport verified, 0 products deviate >1 mm),
  bom.csv/parameters.csv/mount_graph.json, per-subsystem meta JSON,
  view copies, PNG renders.
- **Selfchecks** - reports now buffered to a temp file and moved into
  `exports/` at completion so `GIT2_tree_clean` measures a genuinely
  clean tree instead of the check's own output.
  `selfcheck_overhaul02.py` GEOB exemption list synced with the
  sprint-03 launch/return path surfaces the ball intentionally rides.

Verification (`freecadcmd.exe scripts/freecad/selfcheck_overhaul0N.py`):

- `selfcheck_overhaul03.py`: **73/73 gates PASS** - GIT/DET/PAR/PROV/
  DAG/ASM/FAST/GEO/ENV/XPT/GUI + GEO-I/H/B/T + GEOT-yaw/susan/sweep +
  GEOL + PAR3 (turret-z 4/4, nip gap, lift rail+tie) + DET2
  determinism (all 7 docs rebuild bit-identical).
- `selfcheck_overhaul01.py`: **45/45 gates PASS**.
- `selfcheck_overhaul02.py`: **61/61 gates PASS**.

## 2026-09-24 - Final audit + repo cleanup

- **Final CAD audit** — `selfcheck_rehaul02.py` re-run headless against the
  current tree: 47 checks, `RESULT: ALL PASS` (fresh
  `selfcheck_rehaul02_results.txt`). Flagged conflicts unchanged and
  documented: `VOL_BALL_PATH` vs `FRAME_RAIL_F`/`LIFTER_PED`,
  `LIP_RAMP` (scoop by design).
- **Viewer design audit** — vertex-exact robot bounds measured live:
  17.89" × 17.62" footprint, 13.22" stowed height (inside the 18" cube),
  wheels rest at y=0, lift tops out ~24.5" extended (< 29" cap). 136 BOM
  lines, zero dangling relation links, zero instanced-field qty/drawn
  mismatches, zero NaN transforms.
- **Cleanup** — removed `.playwright-mcp/` browser-test artifacts,
  `scripts/freecad/__pycache__/`, `.devin/spike_expr.py` + stray
  `.devin/mecanum_schematic.png` scratch files, unreferenced
  `exports/renders/fc_screenshot.png`, and the empty legacy
  `exports/{dxf,pdf,step,stl}` dirs (superseded by `prototype_*`).
- **Docs** — `.devin/instructions.md` updated: `selfcheck_rehaul02.py`
  is the current contract gate (was still pointing at rehaul01). Root
  `package.json` tidied (dropped nonexistent `main` + stub test).

## 2026-09-24 - Review fixes (`viewer/`)

- **Connected-parts graph** — `REL` keys can be subsystem-scoped
  (`sub|name`), and link resolution prefers a same-subsystem entry when a
  part name is registered in several. Fixes 'Motor clamp — compact' chips
  jumping to the intake clamp from the feed/flywheel motors, and each
  clamp claiming all three motors as relations.
- **Isolation state** — part **Isolate** now supersedes subsystem
  isolation (mirror of `isolate()` dropping part solo); "Show all" no
  longer leaves a stale active subsystem row with nothing ghosted.
- **Frame hardware** — added the missing bolt pair at the raised
  crown-member junction; drawn instance count now matches the ×24 BOM
  line.
- **Match demo hygiene** — `ball()` shares a cached `SphereGeometry` per
  radius (the demo spawns ~10 balls/run — no more per-run GPU buffer
  growth); Launch Demo restores the prior Animate state instead of
  leaving the toggle on; lift ball rest height corrected in field mode
  (was floating ~0.65" over the tiles).

## 2026-09-23 - Part Explorer + demo realism pass (`viewer/`)

- **Part Explorer** — new `Parts` tab lists all 130 BOM lines grouped by
  subsystem with live filter; click highlights every placed instance and
  frames it. Entries now track placed objects (`e.objs`) and carry a
  hand-built **relations graph** (`e.links`) — the inspector renders
  clickable "Connected parts" chips (motor→pinion→axle→bearing→wheel,
  winch→spool→rope→pulleys→stages, hubs→wire runs, …) plus Prev/Next BOM
  stepping. Scene click-picking now selects the whole entry.
- **Detail pass 2** — motor split clamps + encoder caps/ports, axle washers,
  floating-roller slide blocks + cheek slots, agitator servo horn, column
  base flange, yaw homing magnet + hall sensor, hood pivot bolts, launcher
  top brace, spool rope windings, rope guide eyelet, cradle foam liner,
  USB ferrite bead, powerpole pair at the switch.
- **Match demo realism** — intake rollers/feed wheel/flywheels/agitator are
  now gated per phase (`anim.gates`); pickups sweep in a two-stage path
  (floor slide → throat arc) then roll down the hopper incline visibly;
  every launch now **rises up the clear column first** (`riseLaunch`) before
  the ballistic lob; the FLOWER deposit visibly diverts a NECTAR out the
  column port and down the load chute into the cradle before the lift runs.
- **Spectator camera** — controls stay live during the demo: any drag takes
  a free camera ("Resume cinematic camera" button hands control back).
- Anim lists split (`anim.intake/feed/fly`) for per-phase gating.

## 2026-09-23 - Realism pass + scripted match demo (`viewer/`)

- **Procedural textures** (no external assets): canvas-drawn alliance number
  plates (27475), 36h11-style AprilTag faces, foam-tile waffle + bump, motor
  wrap labels, hub faceplate, gaffers-tape sheen, radial contact-shadow blob.
- **Robot detail** — full wiring loom (6 motor power pairs, 5 servo PWM
  extensions + stage-riding tilt lead, 4 encoder/sensor JST runs, battery →
  main switch → hub power trunk, hub RS485 link, camera USB through an
  8-circuit slip ring on the feed column), sealed bearings with flange bolts,
  motor cooling ribs + label bands + brass pinions, #25 roller chain with pin
  detail, nylock axle nuts, rail end caps, hub LEDs/labels/bolts, battery
  strap buckle + XT30, zip ties, instanced bolt fields on every major plate.
- **Field detail** — walls rebuilt as aluminum kick rail + clear polycarb
  panel + top cap + posts + corner posts; textured AprilTags on walls and
  hive-cell undersides; hive cells gain screen insets, mouth rims, and pivot
  bearings; flowers gain throat tube, petal collar, leaves, pipe collars and
  a base block; tape markings (center line, hive approach, zone borders).
- **Match Demo** (`viewer/js/demo.js`) — ~40 s scripted blue-alliance match:
  autonomous pollen intake sweep, AprilTag aim + 3-ball cell lob, teleop
  mecanum strafe to the nectar stash, 2 nectar launches that tip the hive,
  corner approach + lift deposit into the flower mouth, loading-zone park.
  Cinematic chase/fixed cameras, phase captions, wheel-spin and body-bob
  while driving, balls arc on bezier trajectories and stay in the cell.
- `viewer/serve.py` — no-store dev server; `python -m http.server` lets the
  browser cache ES modules and served stale code during iteration.
- `window.__bio` exposes { scene, robot, groups, entries, anim, refs, demo }
  for console debugging.

## 2026-09-23 - Flower deposit lift (`viewer/`)

Design-review finding (user): the robot could not reliably score in FLOWERS —
the flower mouth is a ~4" (101.5 mm) opening at ~21.5" (§9.7) for a 3.6" (91 mm)
NECTAR, leaving ~5 mm radial clearance; a flywheel lob into that window was
judged too unreliable. Replaced with a lift-and-place deposit (the FreeCAD
architecture's original nectar-lifter intent).

- **New subsystem `lift`** — two-stage cascade mast on slim guide rails in the
  rear-left corner (rails stand on the side-rail top flange, clear of the
  wheel), dyneema rigged from a continuous-servo winch: dead-end to stage 1,
  return over a traveling pulley to stage 2 (live rope legs update per frame).
  Hard-stop collars cap travel per R105/G416.
- **Load path reuses the feed column** — a servo Y-flap below the turret deck
  kicks one ball out a side port on the column (below the rotating-plate
  sweep), down a PETG load chute through a slot in the tower cheek, into the
  deposit cradle. No second ball path through the frame.
- **Cradle** — PETG C-cup cantilevered forward of the mast so its rise path
  clears the Ø6.7" rotating turret plate and the tower cheeks; micro-servo
  tips it at ~22" to drop NECTAR into the flower mouth. Staged NECTAR ball
  falls free on tip and re-seats on retract.
- **Compliance update** — servos 4→7 of 8 (winch, diverter, tilt); motors stay
  8/8; robot no longer claims "never leaves the cube": starts inside R101,
  lift tops ~26" against the R105 29" cap, footprint stays 18×18.
- **UI** — `Lift` toolbar button animates extend → tip → ball drop; callouts
  for the mast, cradle, and diverter; compliance panel updated.

## 2026-09-22 - Interactive Three.js design review (`viewer/`)

User-directed pivot away from the FreeCAD pipeline for visualization: a
self-contained Three.js design-review app covering the full competition
robot concept — no CAD software needed (`cd viewer; python -m http.server
8017`).

- **Robot** — 6 subsystems, ~130 placed parts merged into 70 BOM lines:
  17.5×17.5×13.3" mecanum chassis (never leaves the 18" cube),
  over/under intake → inclined hopper → feed column through the turret
  axis → dual-flywheel 360° turret launcher with AprilTag camera.
  Parametric part library in `js/parts.js` (U-channel, mecanum/omni
  wheels, gears, motors, servos, electronics).
- **Review features** — per-part inspector + tooltip pick, subsystem
  tree with isolate/X-ray/visibility toggles, exploded-view slider,
  callout labels, 18" sizing-cube overlay, camera presets, animated
  mechanisms (rollers, flywheels, turret slew, hood, agitator) and a
  launch demo that lobs a POLLEN into the HIVE cell and tips it.
- **Field at scale** — 36-tile 12' field, 12" walls, pivoting red/blue
  HIVE cells with underside AprilTags, 4 FLOWERS, loading zones, and
  manual-accurate staged elements (POLLEN in flowers/on floor, NECTAR in
  up-cells + alliance areas per TU01 §9).
- Compliance panel tracks R101/R105 + motor/servo counts. Vendored
  three.js r170 (matches `viewer/package-lock.json`); no build step, no
  external requests.

## 2026-09-21 - Rehaul sprint-02: intake + transfer component fidelity

Sprint-02 rebuild of the intake and transfer subsystems in
`master_robot.FCStd`, `intake_concept_v01.FCStd`, and
`transfer_concept_v01.FCStd` - all on the shared `partkit.py`
vocabulary, all dims expression-bound to `Parameters`.

- **Intake** - bored cheek plates (7 bores: shaft, pivot, bearing,
  mount, servo-strap), ribbed roller tube + 8 mm shaft + flanged
  bearings, bored pivot bosses with *stub* axles (no cross-shaft -
  clears the O91 ball path), pivot servo in the rail-mouth pocket on
  the bottom flange + clamp strap, mount L-brackets on the side-rail
  inner faces, intake lip sill. `VOL_INTAKE` widened to 340 for the
  shaft tips.
- **Transfer** - chamfered channel floor, bored walls (hinge bore +
  servo bolt pattern) with outer faces flush against the drive-motor
  inner faces (lane 101 mm > O91), saddle supports, bored diverter
  paddle on a 6 mm hinge axle through wall bushings, servo + horn on
  the wall outer face, route markers, `VOL_CHANNEL_CLEAR` +
  `VOL_BALL_PATH` probes. `VOL_TRANSFER` widened/dropped to cover the
  axle tips + saddle feet.
- **New aliases** - `nectar_dia`, `pollen_dia`, `paddle_sweep_deg`,
  roller/bearing/servo/bolt dims, channel sheet dims - all logged in
  `robot-parameters.md`.
- **Flagged integration conflicts** (documented, sprint-04 action):
  the straight `VOL_BALL_PATH` probe intersects `LIFTER_PED` (sprint-01
  pedestal sits inside the intake floor lane) and `FRAME_RAIL_F` (the
  intake mouth sits proud of the front rail - balls ride over it).
- **Verification** - `selfcheck_rehaul02.py`: PAR/PROV/DAG/ASM1-4/
  ENV1'/GEO8'/GEO-I/GEO-T/reserves/GUI/determinism/REG signature
  checks - ALL PASS. Determinism verified across two rebuilds and a
  mirror-tree rebuild (0 sig diffs). Exports: STL 174k facets, STEP
  28.9k entities, 16 PNG renders + master SVG views, view-state
  injected into all files.

## 2026-09-20 - Rehaul sprint-01: partkit drivetrain (component fidelity)

User-directed rehaul: replace the primitive placeholder chassis/drivetrain
with component-grade geometry in both `master_robot.FCStd` and
`drivebase_concept_v01.FCStd`, driven from a new shared kit
`scripts\freecad\partkit.py`. All changes remain expression-bound to the
`Parameters` sheet.

- **partkit.py** — predicate-based edge selection (`pred_axis`,
  `pred_radius`, `pred_at_z`, `pred_combine`), filleted plates, U-channel
  extrusions (cut solid + hole grid + shaft notches), shafts, bored hubs,
  bearing blocks, bored motor face plates, fused roller+pin bodies, and
  `mecanum_wheel` returning an `App::Part` carrier. TOOL-prefixed
  construction intermediates grouped under a `Tools` container.
- **Frame ring** — `FRAME_RAIL_*` (master) / `RAIL_*` (drivebase): real
  open U-channel sections (outer − void − holes − notches), Ø4 hole grid
  on flanges + web, Ø16 shaft notches through the side-rail mouths.
- **Sheets** — filleted `BELLY_PAN` on the lower flange lip; filleted
  `REAR_DECK_L/R` flanking the ball channel, ending forward of the rear
  motors.
- **Wheel assemblies** — `WHEEL_ASSY_*` carriers at ±140/±180 mm (moved
  inboard from ±170 so motors clear the end rails); per wheel a bored
  Ø26 hub, two chamfered Ø92 face plates, and 10 fused roller+pin bodies
  (~45° slant, FTC X-pattern) whose pins seat ~1 mm into the plates.
- **Drive chain** — per wheel: `MOTOR_*` Ø36×60 → `MOUNT_MOTOR_*` face
  plate on the web inner face → `SHAFT_*` 8 mm REX through face plate +
  web notch → `BEARING_*` flange block on the cavity face → cheek
  clearance bore → hub bore.
- **Mount-chain placeholders** — `INTAKE_MOUNT_*` cheek brackets,
  `CHANNEL_SUPP_*` saddles, `POST_SHOOTER_*` uprights +
  `SHOOTER_FLOOR`/`SHOOTER_SIDE_*` plates, `LIFTER_PED`/`LIFTER_BASE`,
  `ELEC_RAIL_*` standoffs — mechanism reps now physically contact the
  frame (0 connectivity islands).
- **Bug fixes during the sprint** — FreeCAD raw `.Shape` stays local for
  carrier children: all analysis/export now uses globalized copies;
  roller bodies fused with their pins (roller was unreachable inside
  carrier space); duplicate `Tools` group auto-rename (`Tools001`)
  removed.
- **Pipeline** — `render_png.py` (new shaded z-buffer PNGs, master +
  drivebase ×4 views), `render_views.py` and `export_prototypes.py`
  globalize shapes and exclude `TOOL_*`; `make_view_copy.py` styles both
  files + `*_view.FCStd` copies; new gate `selfcheck_rehaul01.py`
  supersedes `selfcheck_sprint06.py` (retained, runnable on the archived
  sprint-07 baseline).
- **Frozen Appendix-A overlap table** — 108 master pairs + 88 drivebase
  pairs enumerated by class (shaft/bore C1, pin seats C2, mount embeds
  C3, placeholder co-location C7) in `docs\mechanism-architecture.md`;
  undeclared overlaps are failures, never appended.

## 2026-09-20 — Sprint 07: cohesion + realism pass (user-directed)

User feedback: the model read as floating, disconnected primitive
clusters — no visible chassis tying wheels/mechanisms together, and the
tree was two flat containers. Changes (all parametric/expression-bound):

- **Chassis frame** — closed ring of four goBILDA-1120-style 48 mm
  channel rails (`FRAME_RAIL_L/R/F/B`, VENDOR-PENDING per D12) at
  z 0–48, `BELLY_PAN` sheet inside the ring, `REAR_DECK` half-deck over
  the rear bay. Wheels now visibly hang off the frame instead of
  floating.
- **Drive motors** — four `MOTOR_*` (5203 Yellow Jacket ~O36,
  VENDOR-PENDING) extending inboard through the side rails at each wheel
  hub; `WHEEL_PLATE_*_IN/OUT` O92 side discs on every wheel face.
- **Subsystem attachments** — `INTAKE_AXLE` pivot shaft through both
  intake cheeks; `POST_SHOOTER_L/R` uprights from the rear deck to the
  shooter floor; `LIFTER_PED` pedestal (belly pan to mast base) +
  `LIFTER_BASE` plate under the mast column. Nothing floats anymore.
- **Tree organization** — seven `App::Part` groups inside
  `RobotAssembly` (Envelopes, Drivebase, Intake, Transfer, Shooter,
  Lifter, Electronics); every solid assigned by name prefix.
- New aliases documented in `docs\robot-parameters.md`; new intentional
  contact classes (frame/mount overlaps) enumerated in
  `selfcheck_sprint06.py` — sprint-07 section in `exempt_pair`.

Results: master rebuilt to **193 objects / 111 valid solids, 0 invalid**
(was 107/90). Selfcheck ALL PASS. Re-exports: 94-solid STL
(32,360 facets), STEP reimport 95 solids, MANIFEST synced. SVG + PNG
renders regenerated; styled view re-injected into both FCStd files.
True fillets remain deferred — baked fillets would break the
expression-binding contract; the parametric-primitive look is
documented as the placeholder trade-off.

## 2026-09-20 — Viewing/render fix pass (post-epic, user-reported)

User report: the FCStd opened to a black/empty viewport and the SVG
renders looked buggy and sparse. Root causes and fixes:

- **Black viewport on open.** All sprint scripts run headless
  (freecadcmd), so the FCStd carried no view state: FreeCAD invented a
  default camera that could sit inside the opaque `ENV_*`/`VOL_*`
  packaging solids, and "Fit All" zoomed out to the `REF_HIVE`/`REF_FLOWER`
  field markers ~1.2 m away, shrinking the robot to a speck. Fix:
  `scripts\freecad\make_view_copy.py` injects a `GuiDocument.xml` into
  the FCStd zip — hides `ENV_*`/`VOL_*`/`REF_*`/`Origin`, colors the 70
  subsystem solids to match the render palette, and sets an orthographic
  isometric camera (az 45 / el 35.264, fitted). Written into both
  `cad\master_robot.FCStd` (in place; `Document.xml` and all `Shape.brp`
  payloads byte-identical — verified: 107 objects / 90 valid solids /
  88 expression-bound objects unchanged) and `cad\master_robot_view.FCStd`.
- **Buggy-looking SVGs.** The old overlay drew every edge of every solid
  (hidden, interior, and seam edges included) over the fills. The edge
  pass now draws only silhouette edges and sharp (>~25 deg dihedral)
  edges between front-facing faces — `visible_edges()` in
  `render_views.py`. Facets also get a subtle same-hue darker stroke,
  tessellation tightened to 0.5 mm, canvas raised to 1400 px.
- **New shaded PNG renders.** `scripts\freecad\render_png.py` rasterizes
  the same exportable set through a real z-buffer (numpy) so
  interpenetrating solids occlude correctly — impossible in the old
  painter's-order SVG. Writes `exports\renders\master_{front,side,top,
  iso}.png` with the same views and palette; pure-zlib PNG writer, no
  external deps.
- `scripts\freecad\view_robot.py` kept as the live-session restyle
  helper; note: FreeCAD 1.1 does not execute `.py` files passed as
  command-line arguments, so it runs via Macro -> Macros -> Run.

No geometry, alias, or parameter changes; verification counts identical
to the sprint-06 evaluator record.

## 2026-09-20 — Sprint 06: detail + accuracy pass (autonomous build)

Mechanism-level detail on every subsystem plus datasheet-driven corrections.
Still primitive, expression-bound placeholder geometry — never manufacturing
data. Master: 107 objects / 88 solids; export set grows 21 → 71 leaf solids.
(Contract counted "all 8 FCStd" — the repository has **7** live files; all 7
were archived under `cad\archive\*_sprint05_20260920_135103.FCStd` first.)

Geometry added:

- Mecanum roller placeholders: `ROLLER_{FL,FR,RL,RR}_00..09` — 10 per wheel
  (counted on goBILDA schematic 3606-0000-0096), Ø14 × 20 mm cylinders at
  ~45° slant, positions expression-bound (`cos/sin(k * mec_roll_pitch)`),
  FTC X-pattern (FL+RR one slant, FR+RL opposite). Roller surfaces reach the
  Ø96 datasheet diameter; flat-cap ends stay inside `ENV_WHEEL_*`
  (Ø96 × 32 mm) markers added per wheel.
- Secondary detail: `MOUNT_MOTOR_*` plates (drivebase), `PIVOT_MOUNT_L/R`
  cheek bosses (intake + master), `DIVERTER_HORN` servo arm (transfer +
  master), `STUB_SHAFT_L/R` 8 mm REX shafts (shooter + master),
  `STAGE_GUIDE_L/R` + `CRADLE_LIP` (lifter + master), `ELEC_RAIL_L/R`
  hub rails (electronics + master). All Part:: primitives, expression-bound.

Datasheet-driven corrections (sources in `docs/robot-parameters.md`):

- `wheel_width` 25 → 32 mm (goBILDA schematic 3606-0000-0096).
- `motor_dia` 40 → 36 mm (Yellow Jacket 5203 series page).
- `intake_width` 330 → 326 mm — wheel inner faces at ±164 with the cited
  32 mm wheels; keeps ~1.4 mm clearance to the roller envelope.
- `rail_len` reclassified UNVERIFIED (cut length is a choice, not a catalog
  dim); `rail_w`/`rail_h` 48 mm confirmed against the 1120-series page.
- Mass table basis updated: 4 × 207 g wheels + 4 × ~438 g motors — total
  row still ~2.6 kg; overall placeholder total 14.7 kg unchanged.

Exports/renders:

- `export_prototypes.py`: export-set count now computed dynamically (no
  hardcoded 21); manifest prints the computed count. STL: 25740 facets,
  bbox (−218.0, −196.0, −0.0)–(228.6, 196.0, 640.0) — Y grew ±192.5 → ±196
  with the cited 32 mm wheels. STEP reimports 72 solids.
- `render_views.py`: colored/filled per-subsystem facets (painter's
  algorithm) + wireframe edge overlay + legend; added `master_iso.svg`
  (orthographic, az 45° / el 35.264° — true isometric).
- `selfcheck_sprint06.py` — new gate superset of sprint-04: adds the 9
  enumerated overlap-exemption classes, roller count/slant/X-pattern/
  envelope asserts, and updated probes (intake_width 326).

## 2026-09-20 — Sprint 05: prototype exports + renders (autonomous build)

Prototype export pipeline — no model changes (all 7 live FCStd byte-stable
before/after; earlier notes saying "8" were a miscount, corrected sprint-06).
Everything exported is placeholder geometry, labeled
PROTOTYPE / VERIFY BEFORE MANUFACTURING.

Added:

- `scripts\freecad\export_prototypes.py` — exports the 21 robot leaf
  solids (4 wheels, `BATTERY`, `ELECTRONICS`, 15 `MECH_*`) to
  `exports\prototype_stl\master_robot_PROTOTYPE.stl` (3668 facets) and
  `exports\prototype_step\master_robot_PROTOTYPE.step` (ISO-10303-21,
  re-imports ≥21 solids); writes `exports\MANIFEST.md` with the object
  list, exclusion rule, and labels.
- `scripts\freecad\render_views.py` — headless SVG wireframe projections
  (front/side/top) to `exports\renders\` — `freecadcmd` has no GUI
  renderer, so wireframe SVG is the honest approach.
- `exports\MANIFEST.md`, `exports\export_validation.txt`,
  `exports\renders\render_log.txt`.

Docs: build report sprint-05 append; README + instructions list the
export/render commands; requirements marked delivered.

## 2026-09-20 — Sprint 04: master integration + field references (autonomous build)

`master_robot.FCStd` upgraded to 53 objects / 34 leaf solids: every
mechanism's representative solids now placed in the assembly and the
flagged `VOL_*` reserve overlaps resolved. Still placeholder-grade —
primitive bound solids, never manufacturing data.

Changed:

- `VOL_INTAKE` narrowed to 330 mm (`intake_width` 340→330) — clears the
  wheel inner faces; `MECH_INTAKE_CHEEK_L/R` + `MECH_ROLLER` added.
- `VOL_TRANSFER` dropped to floor level (`channel_z` 100→10, the
  through-chassis lane continuous with the intake throat) and ends flush
  at the intake face (length derived by expression, ~228.6 mm);
  `MECH_CHANNEL` + `MECH_DIVERTER` added. The transfer concept keeps its
  standalone 340 mm `channel_len` study.
- `BATTERY` repositioned to the −Y chassis side and `ELECTRONICS`
  belly-mounted — placements now expression-bound (`bat_*`, `elec_*`
  aliases).
- Shooter reps: `MECH_SHOOTER_BODY` (rear plate), `MECH_SHOOTER_HOOD`,
  `MECH_FLYWHEEL_L/R` with inner-face gap = `bore` 100 mm.
- Lifter reps: `MECH_LIFTER_STOWED`, `MECH_STAGE_1/2/3` telescoped inside
  the deployed ghost, `MECH_CARRIAGE`, `MECH_CRADLE` at ~600 mm.
- Field aiming references: `REF_HIVE` (~800 mm past front face, ~300 mm
  launch height — position UNVERIFIED) and `REF_FLOWER` (~546 mm, §9.7
  VERIFIED height; XY UNVERIFIED).
- `intake_concept_v01` + `transfer_concept_v01` updated for the shared
  `intake_width`/`channel_z` values (object sets unchanged).
- `cad\archive\*_sprint03_20260920_120918.FCStd` — timestamped pre-change
  backups of master + intake + transfer staged before reruns.
- NEW `scripts\freecad\selfcheck_sprint04.py` — contract gate
  (named-pair disjointness, full leaf scan, envelope compliance, field
  refs, expression probes, close-no-save hash).

Docs: `robot-parameters.md` gains master integration aliases + a mass
table (14.7 kg placeholder total, all UNVERIFIED); `mechanism-architecture
.md` gains the integration section with declared co-locations;
`open-questions.md` marks the reserve-overlap question resolved.

## 2026-09-20 — Sprint 03: mechanism-level placeholders (autonomous build)

Upgraded every concept file from packaging volumes to mechanism-level
placeholder geometry per D9–D11 (still primitive solids, expression-bound,
never manufacturing data). `master_robot.FCStd` untouched this sprint
(integration is sprint-04).

Added / upgraded:

- `drivebase_concept_v01.FCStd` (21 objects, 12 solids): `RAIL_L`/`RAIL_R`
  goBILDA U-channel side rails 400 × 48 × 48 mm flush with chassis sides;
  wheels/motors unchanged (one motor per wheel, D9).
- `intake_concept_v01.FCStd` (19 objects, 10 solids): `PIVOT_PLATE_L/R`
  side plates + `PIVOT_BOSS` hinge at the rear; `LIP_RAMP` scoop lip
  pitched ~20° at the mouth bottom.
- `transfer_concept_v01.FCStd` (19 objects, 10 solids): `DIVERTER_PADDLE`
  + `DIVERTER_AXIS` hinge at the scoring end; `ROUTE_POLLEN` (up to
  shooter) and `ROUTE_NECTAR` (to lifter hopper) route markers.
- `shooter_concept_v01.FCStd` (18 objects, 9 solids): universal bore
  `bore` = 100 mm bound between flywheel inner faces (D10, Nectar-capable
  is settled); `MUZZLE_CLEAR` 110 mm; `HOOD` over muzzle, `BACKSTOP`
  behind the bore, `FEED_INLET` at the −X face.
- `lifter_concept_v01.FCStd` (20 objects, 11 solids): three nested cascade
  stages `STAGE_1/2/3` inside the deployed ghost, `CARRIAGE` on the inner
  stage top, `CRADLE` riding it at ~600 mm, labeled `HARD_STOP` marker at
  the outer stage top (R105 physical-stop placeholder).
- NEW `scripts\freecad\build_electronics_concept.py` →
  `cad\electronics\electronics_concept_v01.FCStd` (14 objects, 5 solids):
  chassis volume reference + disjoint `BATTERY`, `HUB_CTRL`, `HUB_EXP`
  REV-style placeholders (VENDOR-PENDING).
- `cad\archive\*_sprint02_20260920_112157.FCStd` — timestamped backups of
  all five upgraded targets staged before their geometry-changing reruns.

Docs: `robot-parameters.md` extended to the full alias union; the
Nectar-shooter open question is closed per D10 in `open-questions.md`;
`mechanism-architecture.md` describes mechanism-level geometry.

## 2026-09-20 — Mechanism decisions recorded (sprint-03 scope setter)

- Drivetrain: 4× 96 mm goBILDA mecanum, one motor per wheel (D9).
- Shooter: dual flywheel, universal ~100 mm bore — Nectar-capable (D10).
- Lifter: top-mounted cascade elevator with Nectar cradle (D11).

## 2026-09-20 — Sprint 02: mechanism concept placeholders (autonomous build)

Second autobuild slice: goBILDA-oriented concept placeholders for the
two-phase scoring architecture (D7/D8).

Added:

- `scripts\freecad\build_intake_concept.py` →
  `cad\intake\intake_concept_v01.FCStd` (15 objects, 6 solids): floor intake
  at the chassis front (+X) with `THROAT_CLEAR` 120 × 110 mm opening,
  two floor-level rollers, chassis-edge reference.
- `scripts\freecad\build_transfer_concept.py` →
  `cad\transfer\transfer_concept_v01.FCStd` (15 objects, 6 solids):
  `CHANNEL` clear 110 × 110 mm cross-section spanning intake (+X) to
  scoring (−X) zones with wall guides and zone markers.
- `scripts\freecad\build_shooter_concept.py` →
  `cad\scoring\shooter_concept_v01.FCStd` (15 objects, 6 solids):
  Pollen-primary housing, twin VENDOR-PENDING flywheels, 90 mm muzzle,
  `LAUNCH_DIR` +X indicator aimed toward the Hive cell.
- `scripts\freecad\build_lifter_concept.py` →
  `cad\endgame\lifter_concept_v01.FCStd` (15 objects, 6 solids):
  `LIFTER_STOWED` inside the 457.2 mm start cube (top-mounted),
  `LIFTER_DEPLOYED` ghost reaching 610 mm inside the R105 expansion
  volume, `CRADLE` 120 × 120 mm at ~570 mm.
- `master_robot.FCStd` extended to 36 objects / 19 solids / 39 aliases:
  `VOL_INTAKE`, `VOL_TRANSFER`, `VOL_SHOOTER`, `VOL_LIFTER_STOWED`,
  `VOL_LIFTER_DEPLOYED` mechanism packaging volumes — sprint-01 objects
  unchanged.
- `drivebase_concept_v01.FCStd`: wheels/motors relabeled goBILDA
  VENDOR-PENDING with `VendorRef` properties; geometry unchanged.
- `cad\archive\master_robot_sprint01_20260920_091818.FCStd` — timestamped
  backup of the sprint-01 master taken before the extension.
- `docs\robot-parameters.md` rewritten: 70-alias union table, status enum
  VERIFIED | UNVERIFIED | VENDOR-PENDING.

Verification performed: all six scripts run twice via `freecadcmd.exe` —
exit 0, identical object lists, no strays; reopen/recompute clean; delta
probes move bound geometry exactly (throat_clear_w +20 % → +24 mm,
channel_w +20 % → +22 mm, muzzle_clear +20 % → +18 mm, reach_z +20 % →
+122 mm); sprint-01 master preserved in `cad\archive\`.

## 2026-09-20 — Team decisions recorded

- Project root confirmed: `C:\Users\pmsma\OneDrive\Documents\BIOBUZZ-Robot`
  (mission's `C:\Users\pmsma\Documents\...` path does not exist).
- Build ecosystem decided: **goBILDA** (purchase pending — vendor dims stay
  UNVERIFIED until parts/datasheets confirm).
- Scoring architecture decided: **two-phase** — Pollen shooter into the Hive
  for early game; top-mounted Nectar lifter for Flower tops in the final
  60 s of TeleOp. See `docs/design-decisions.md` D6–D8 and
  `docs/open-questions.md` for follow-ups.

## 2026-09-19 — Sprint 01: CAD foundation (autonomous build)

Initial foundation generated by the autobuild loop.

Added:

- Directory tree: `cad\{archive,drivebase,intake,transfer,scoring,endgame,
  electronics,library}`, `scripts\{freecad,validation}`,
  `exports\{renders,prototype_stl,prototype_step,prototype_dxf}`, `docs`,
  `.devin`.
- `scripts\freecad\build_master_robot.py` → `cad\master_robot.FCStd`
  (31 objects, 14 solids): `Parameters` spreadsheet with 19 bound aliases;
  `ENV_START` 457.2 mm cube (VERIFIED, R102); `ENV_EXPANSION`
  457.2 × 609.6 × 736.5 mm (VERIFIED, R105); `VOL_DRIVEBASE` packaging volume;
  4 wheel placeholders; battery + electronics placeholders; `COORD_REF`
  App::Part with three axis-indicator solids at the world origin.
- `scripts\freecad\build_drivebase_concept.py` →
  `cad\drivebase\drivebase_concept_v01.FCStd` (19 objects, 10 solids):
  `Parameters` sheet with 10 bound aliases; chassis plate, 4 wheels,
  4 motor placeholders — all expression-bound.
- Full documentation set under `docs\` plus `.devin\instructions.md`.

Verification performed:

- Each script run twice via `freecadcmd.exe` — exit 0, identical object lists,
  no duplicated objects, no stray files under `cad\`.
- Both FCStd reopen and recompute cleanly; every solid valid with volume > 0.
- Mirror-tree test: scripts copied to an empty `%TEMP%` tree rebuild their
  FCStd under the mirrored `cad\` path (proves `__file__`-relative paths).
- Delta test: editing `chassis_length`, `wheel_dia`, `wheel_x_offset` in the
  sheet moves bound geometry by exactly the applied delta.

Known caveats: every non-envelope dimension is an UNVERIFIED placeholder —
see `docs\robot-parameters.md`. Intake/transfer/scoring/endgame subsystems
have no geometry yet; see `docs\mechanism-architecture.md`.

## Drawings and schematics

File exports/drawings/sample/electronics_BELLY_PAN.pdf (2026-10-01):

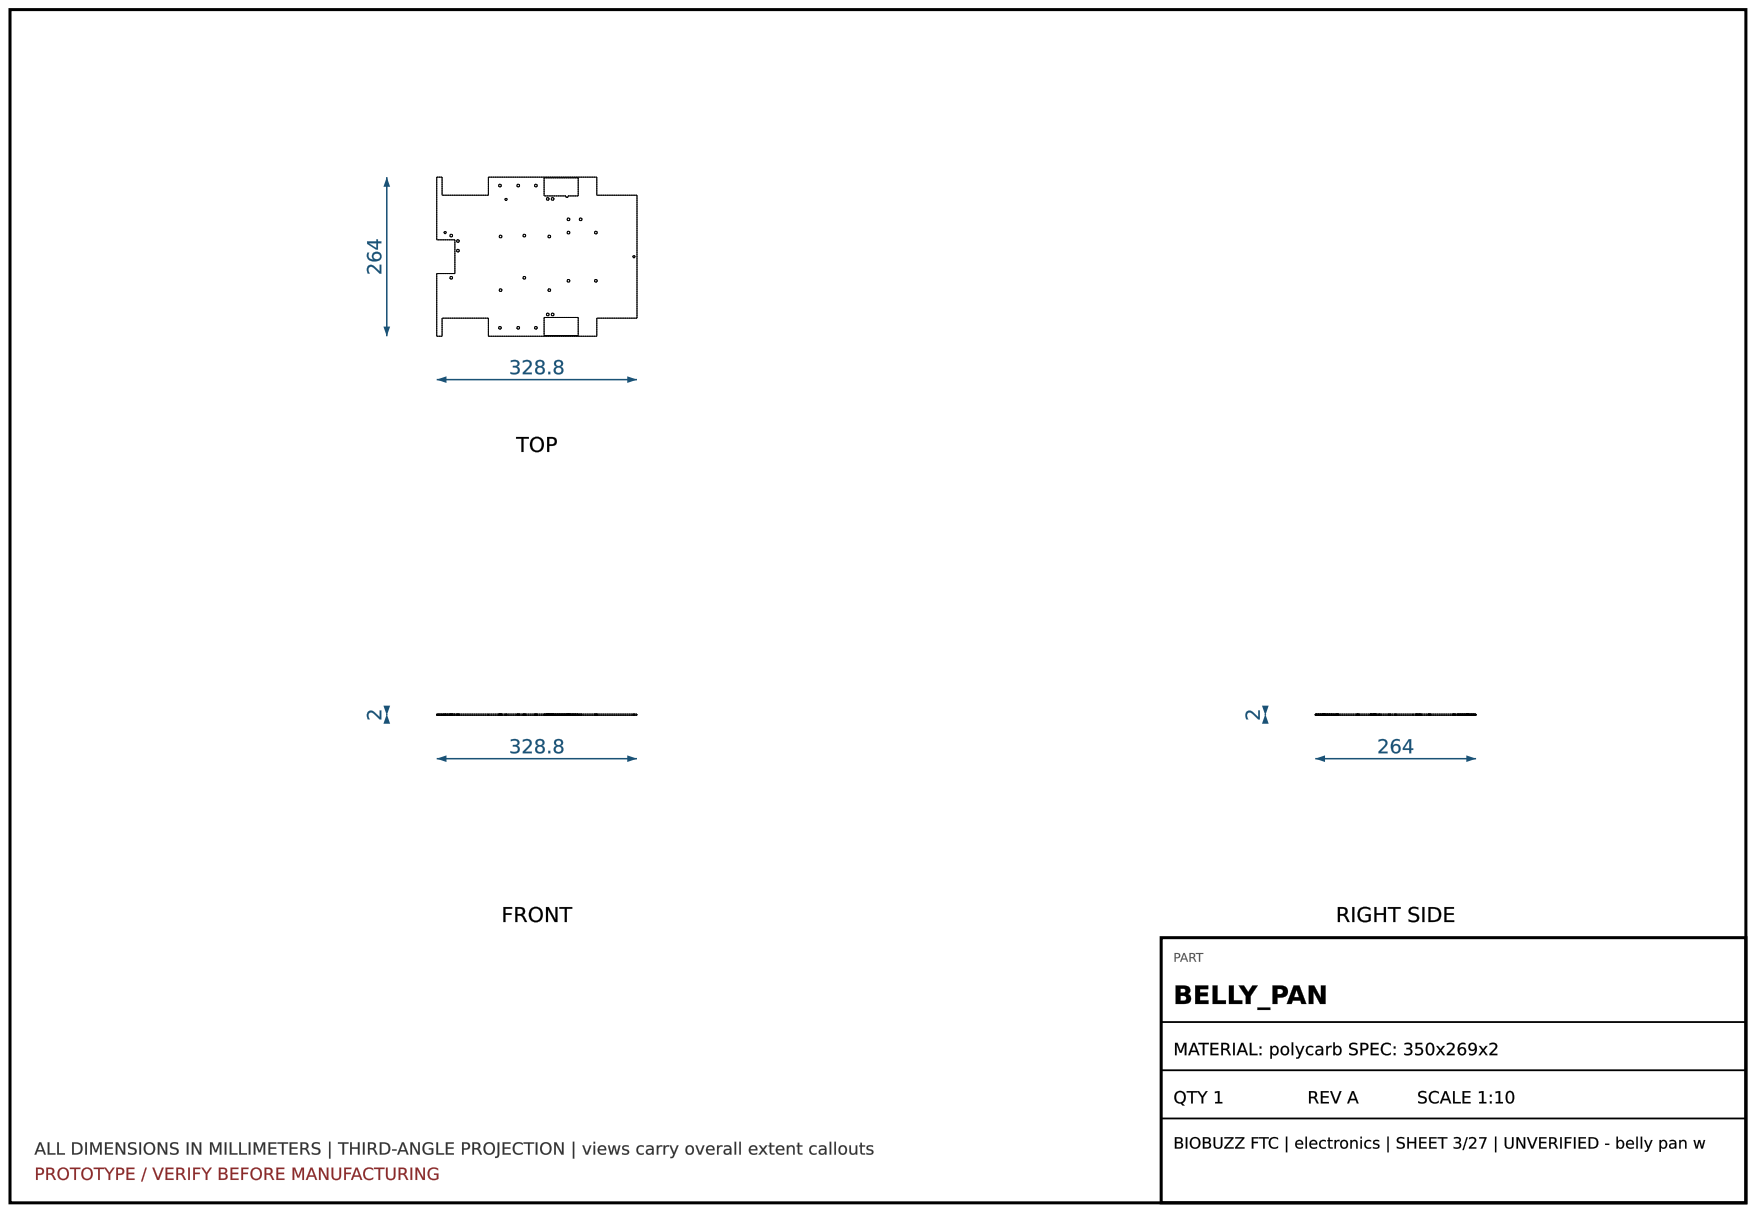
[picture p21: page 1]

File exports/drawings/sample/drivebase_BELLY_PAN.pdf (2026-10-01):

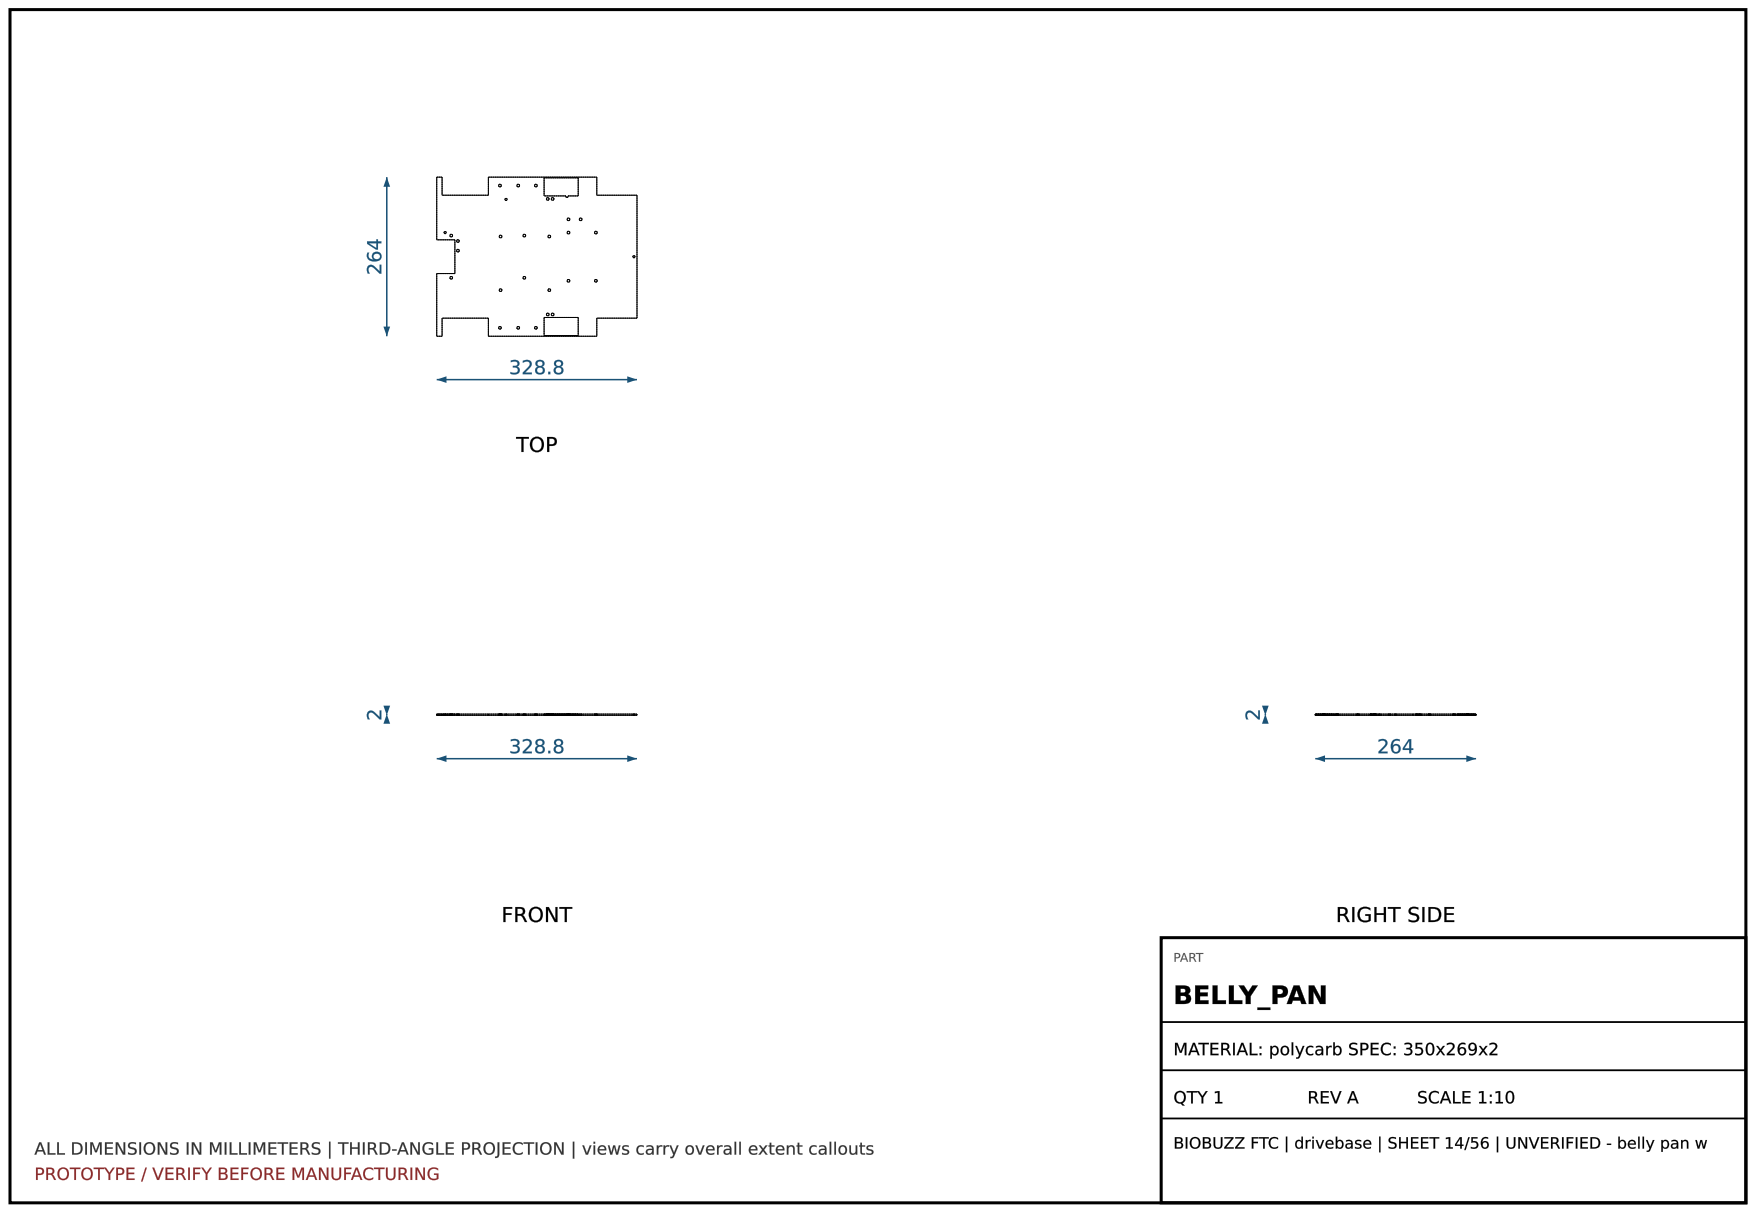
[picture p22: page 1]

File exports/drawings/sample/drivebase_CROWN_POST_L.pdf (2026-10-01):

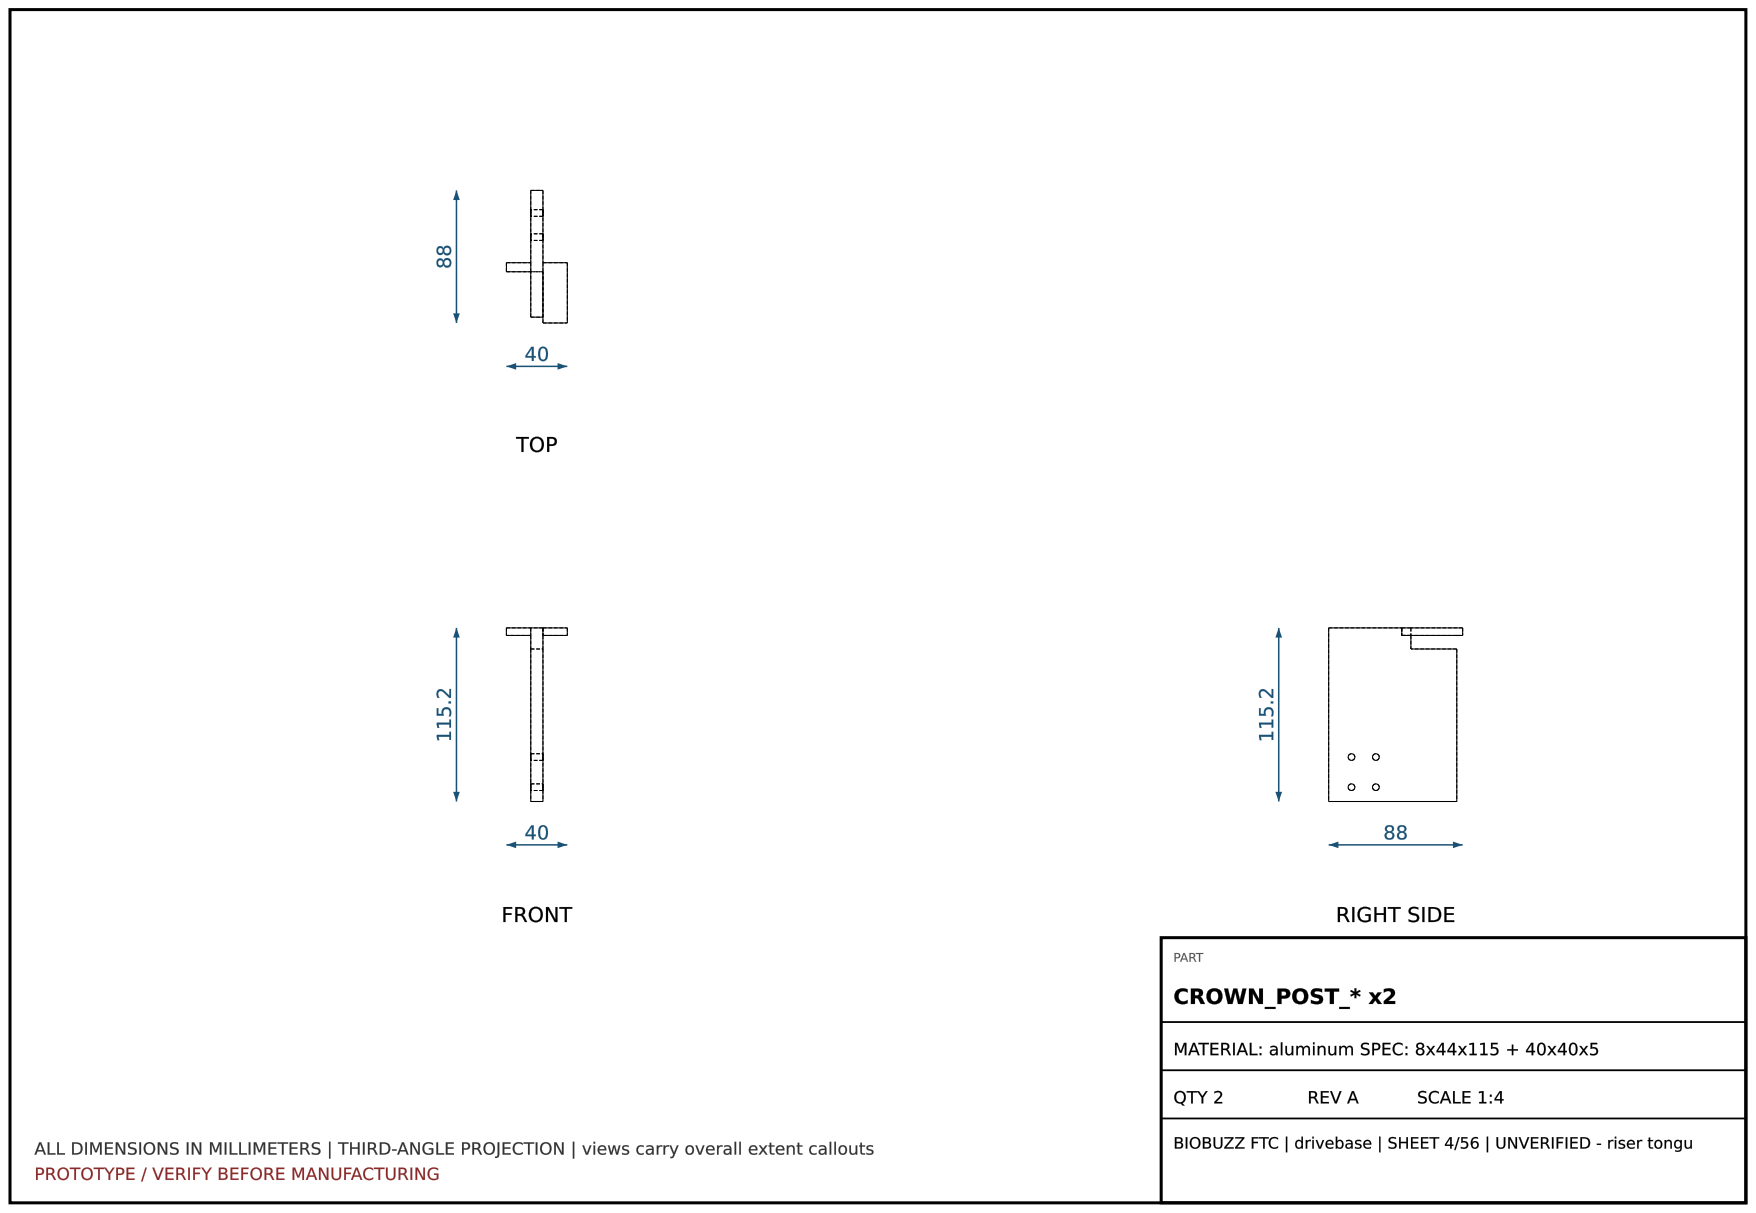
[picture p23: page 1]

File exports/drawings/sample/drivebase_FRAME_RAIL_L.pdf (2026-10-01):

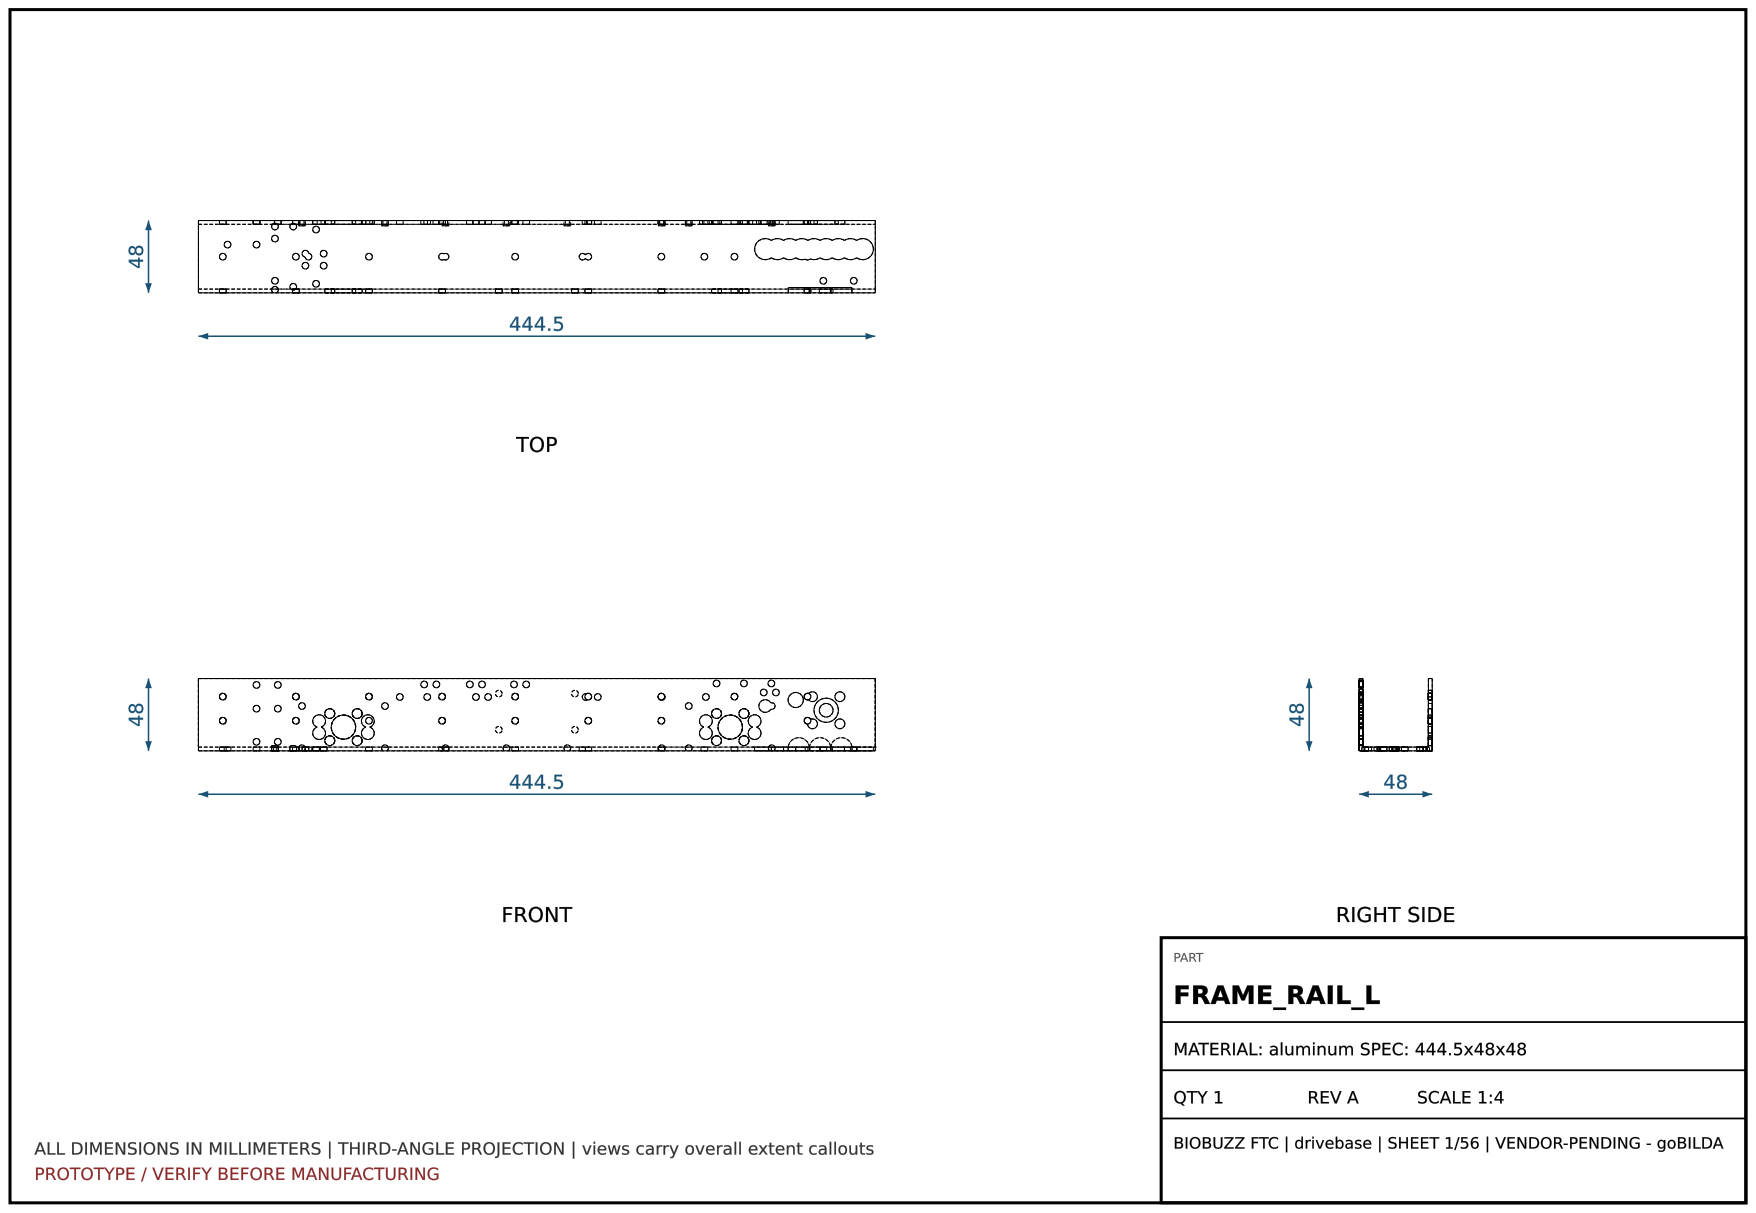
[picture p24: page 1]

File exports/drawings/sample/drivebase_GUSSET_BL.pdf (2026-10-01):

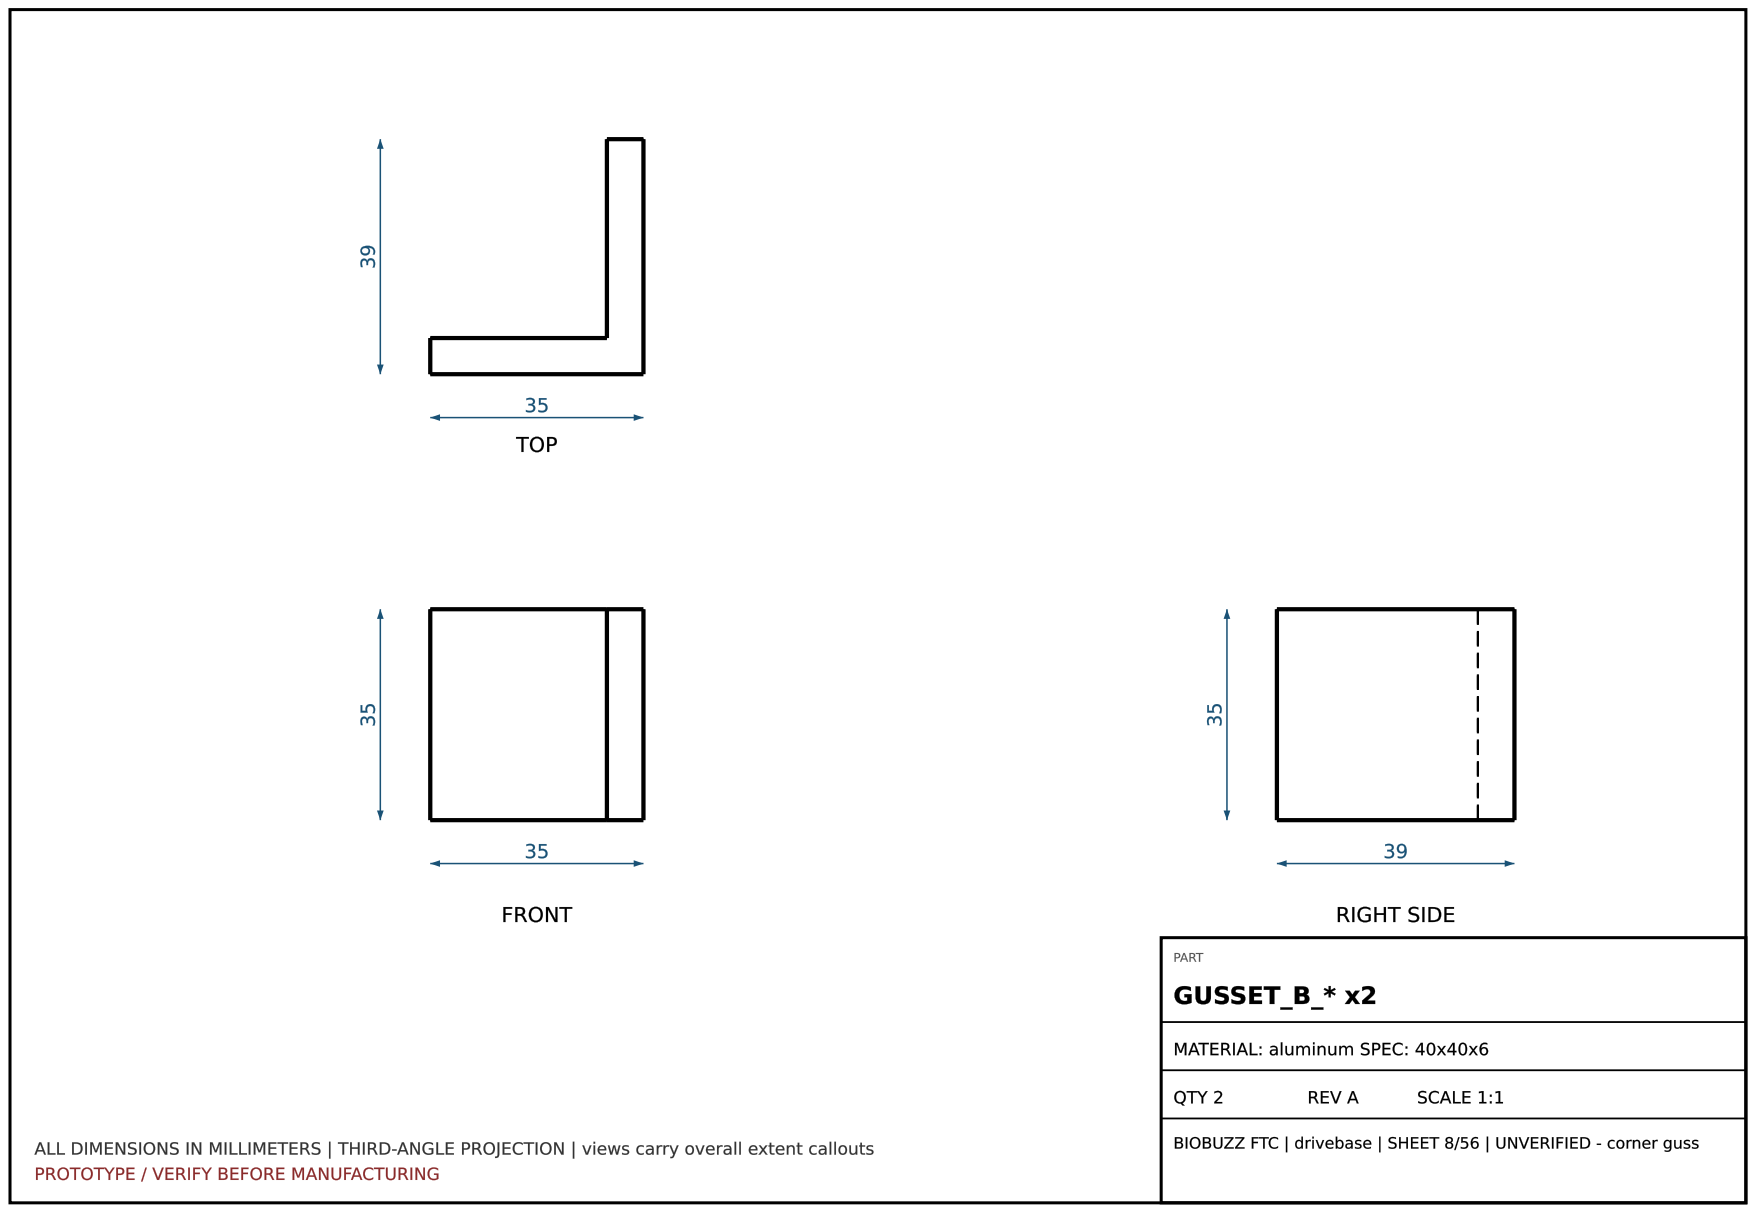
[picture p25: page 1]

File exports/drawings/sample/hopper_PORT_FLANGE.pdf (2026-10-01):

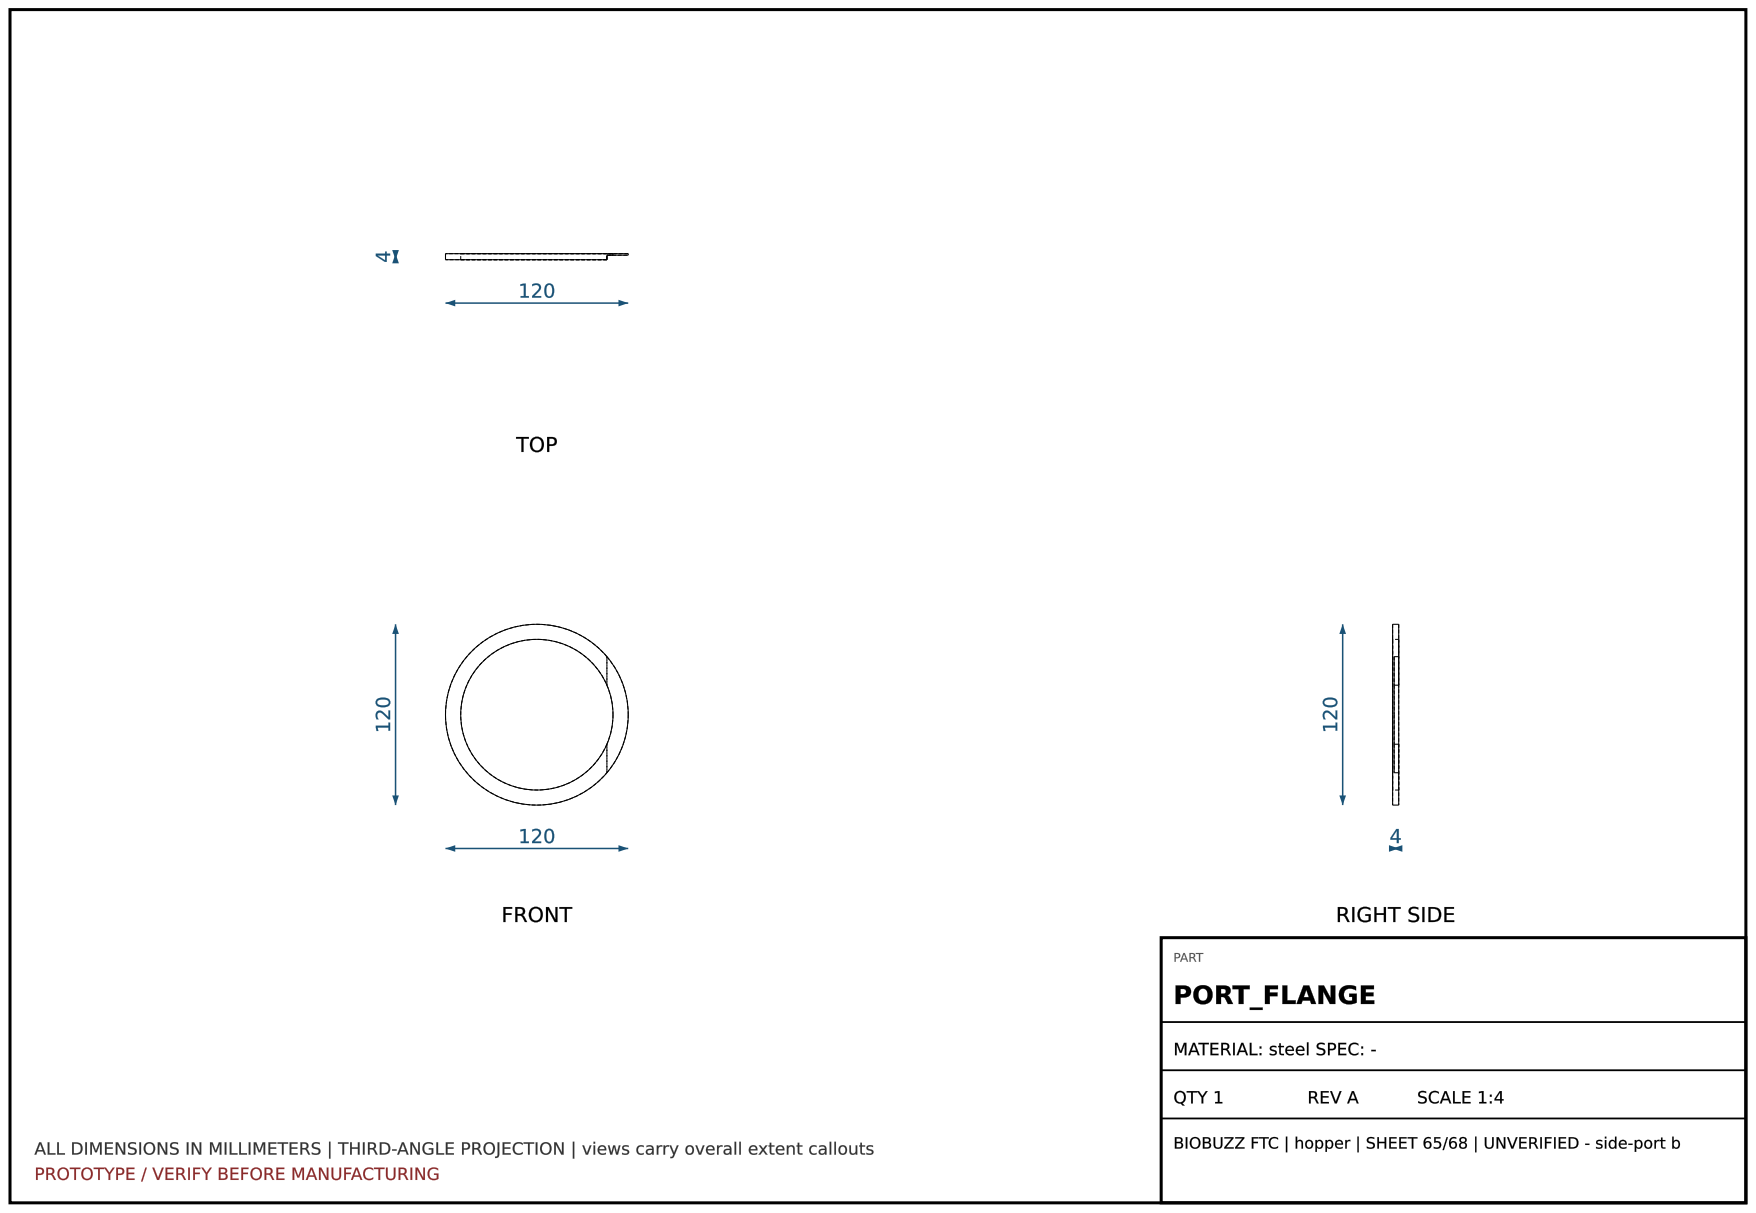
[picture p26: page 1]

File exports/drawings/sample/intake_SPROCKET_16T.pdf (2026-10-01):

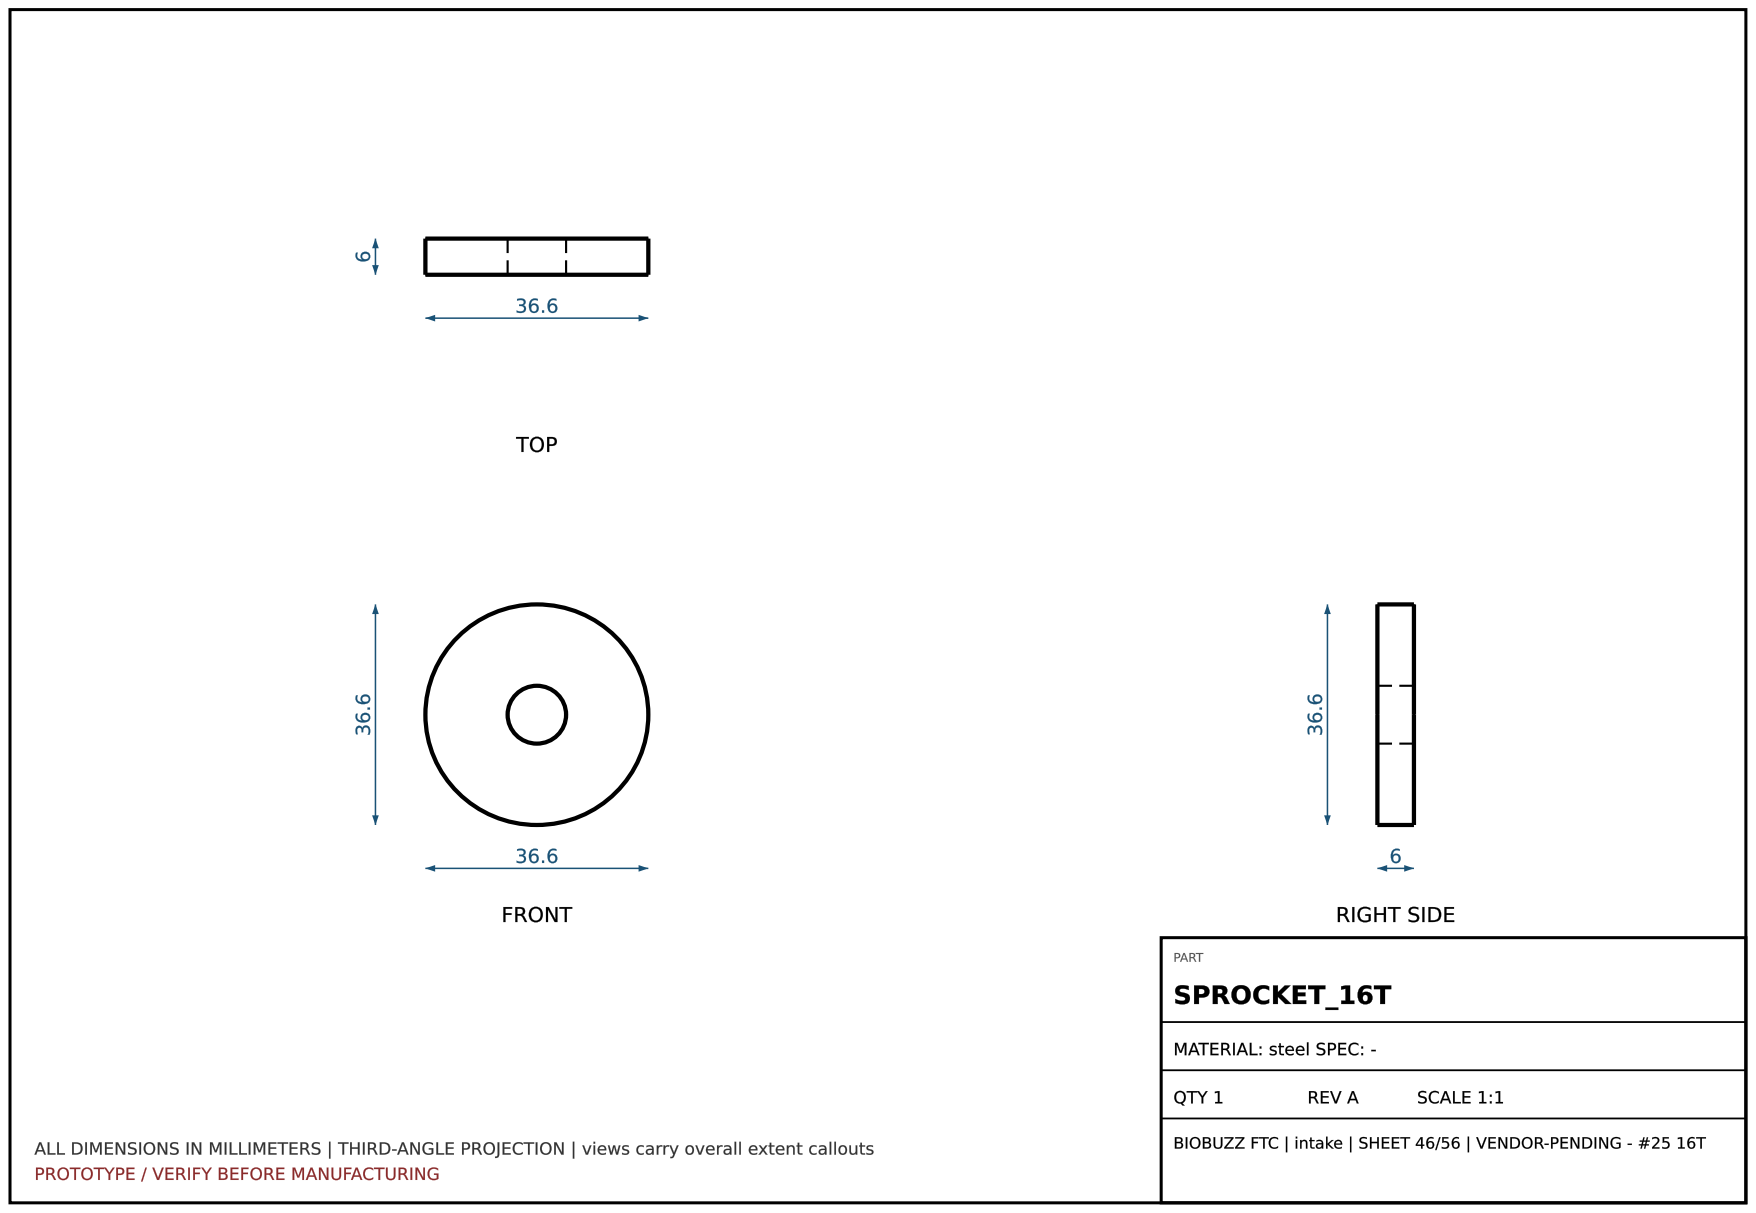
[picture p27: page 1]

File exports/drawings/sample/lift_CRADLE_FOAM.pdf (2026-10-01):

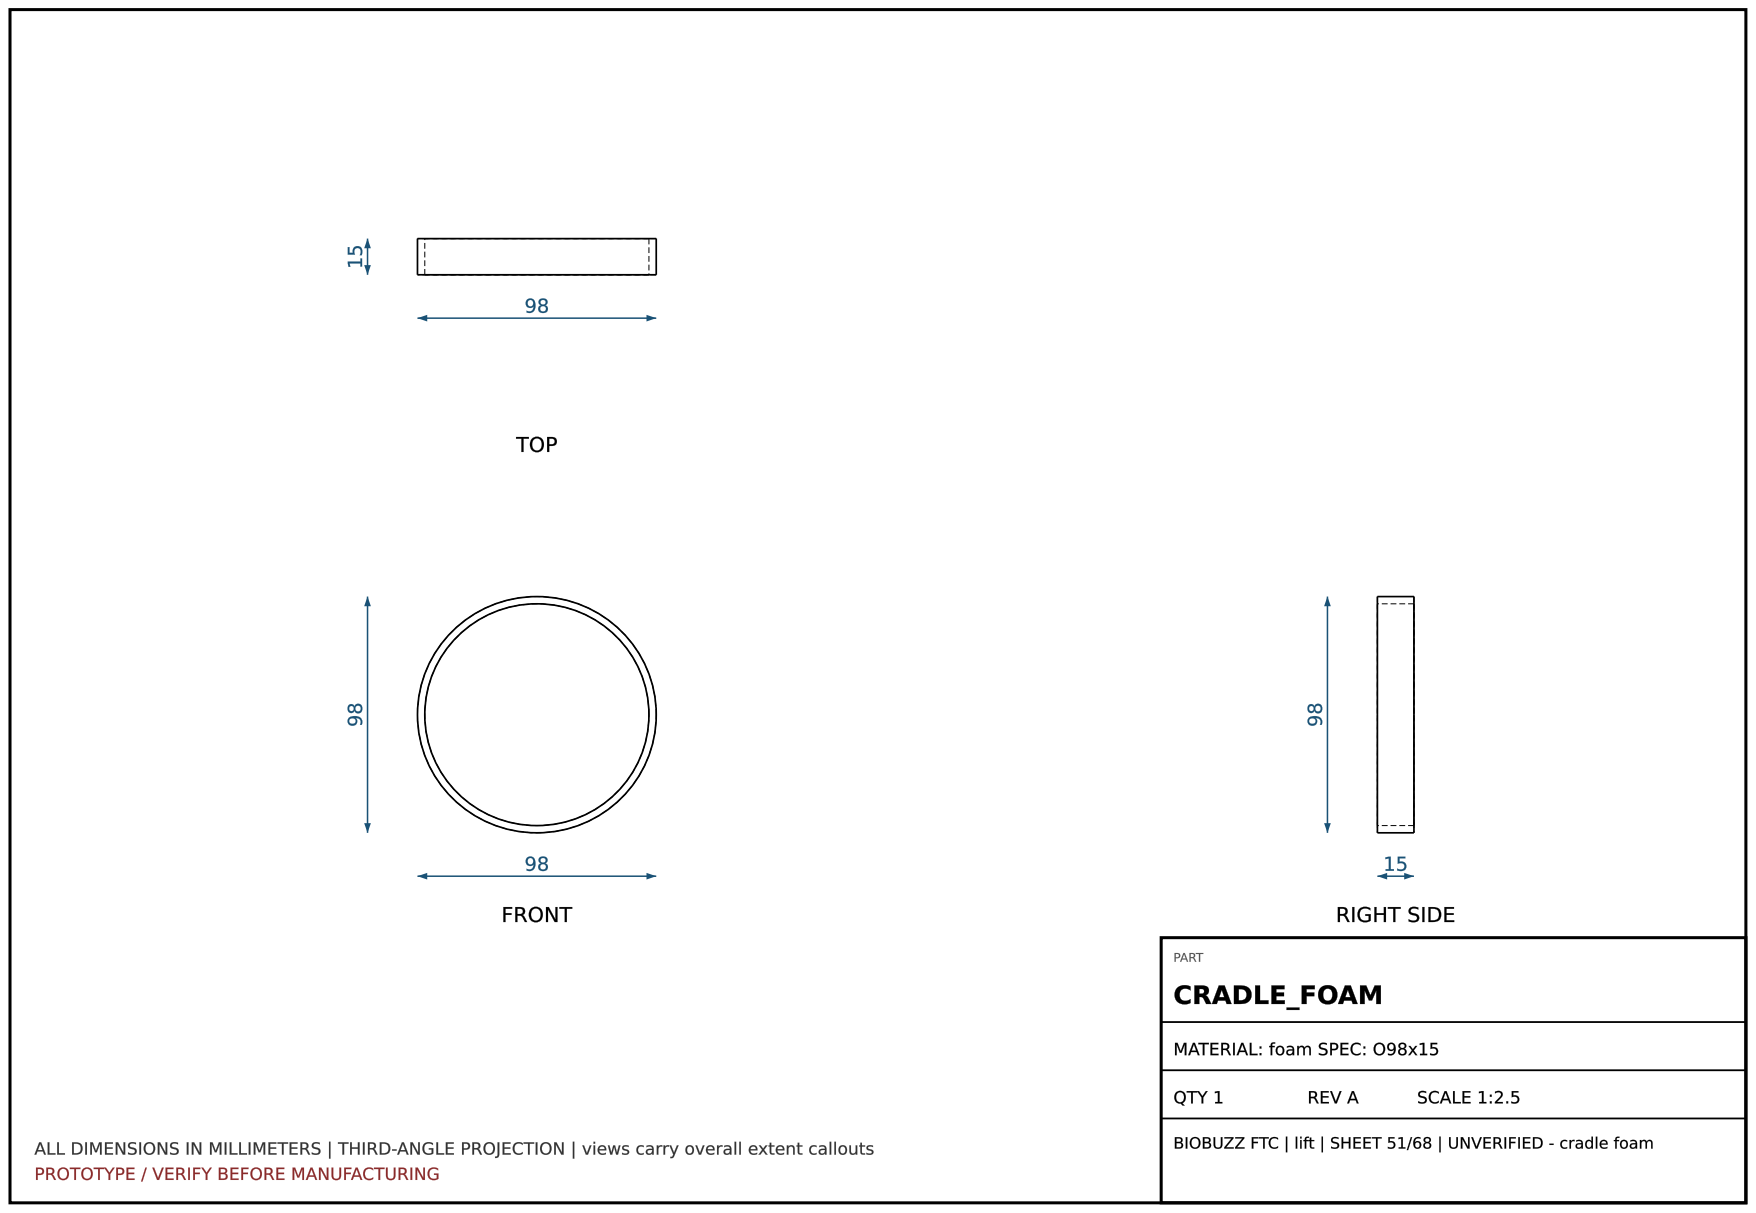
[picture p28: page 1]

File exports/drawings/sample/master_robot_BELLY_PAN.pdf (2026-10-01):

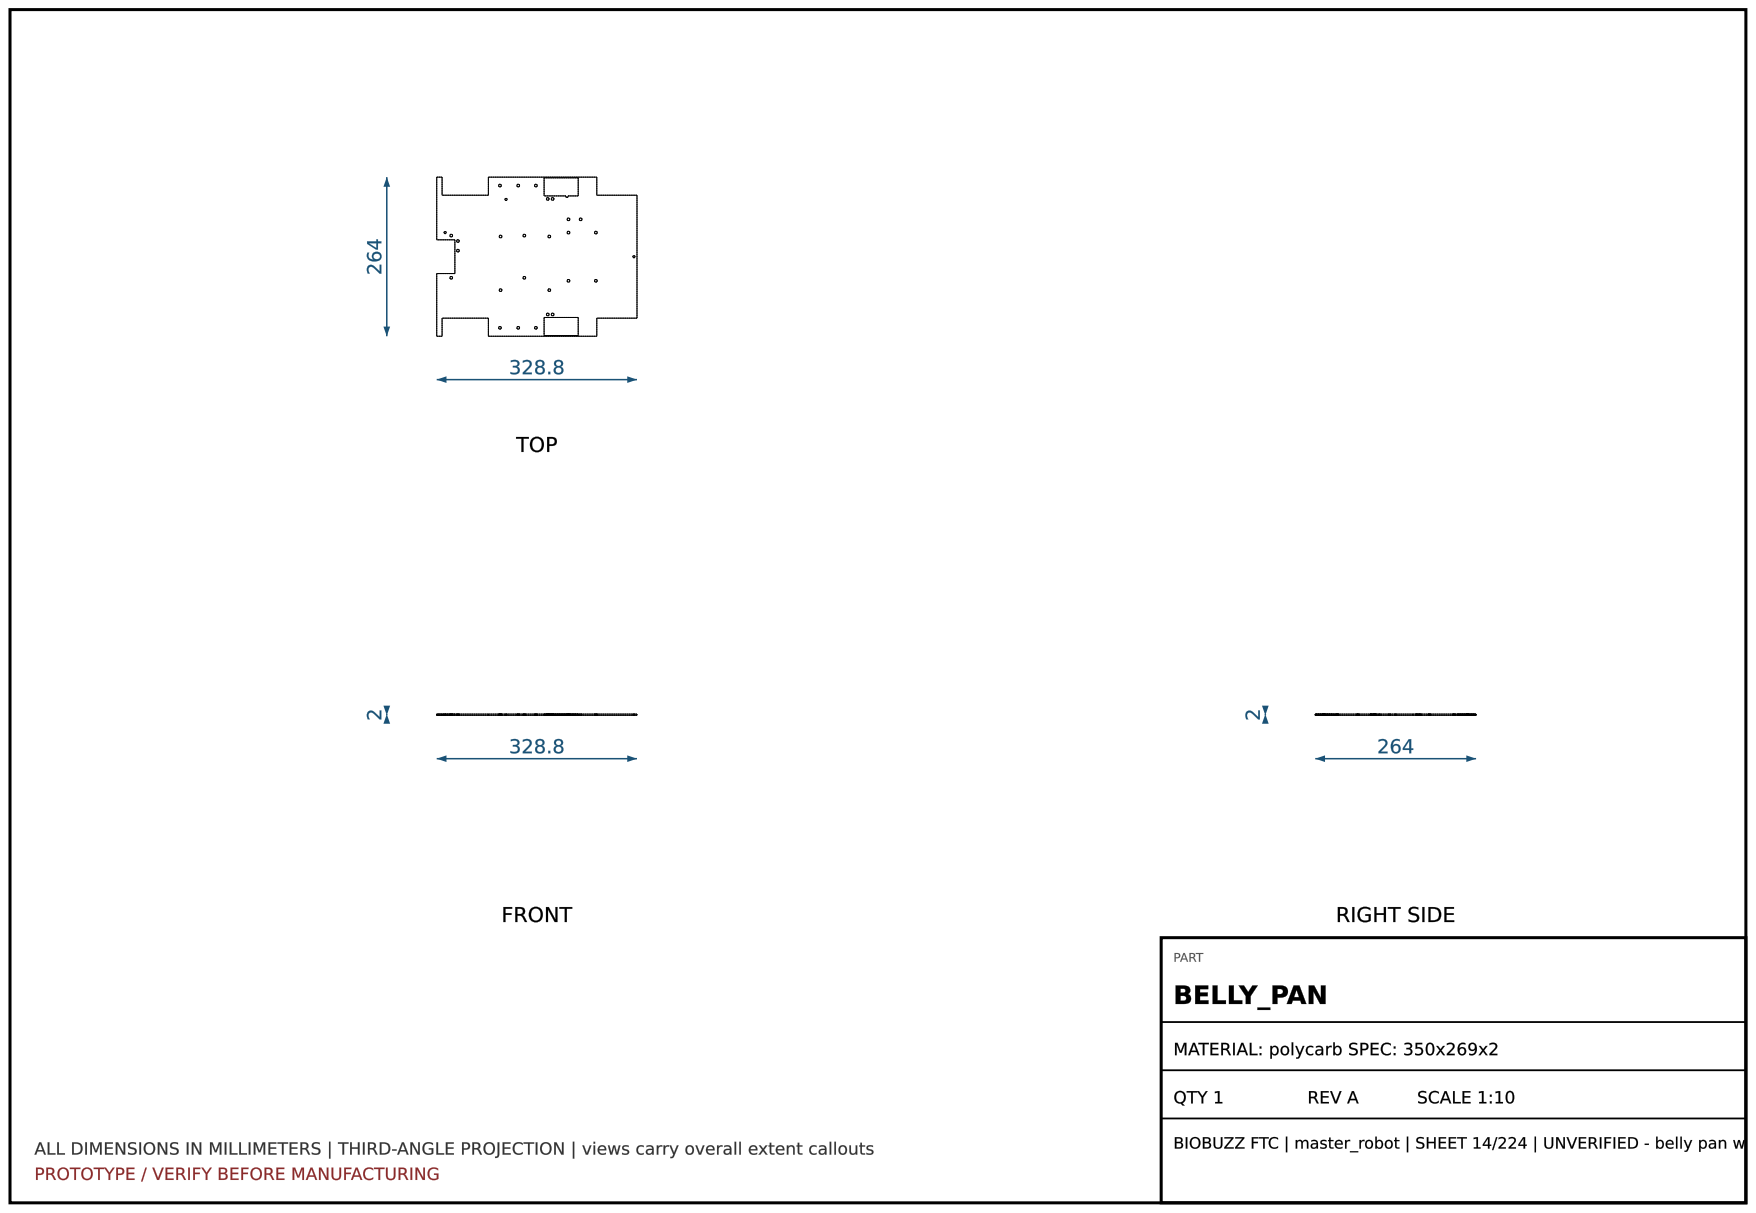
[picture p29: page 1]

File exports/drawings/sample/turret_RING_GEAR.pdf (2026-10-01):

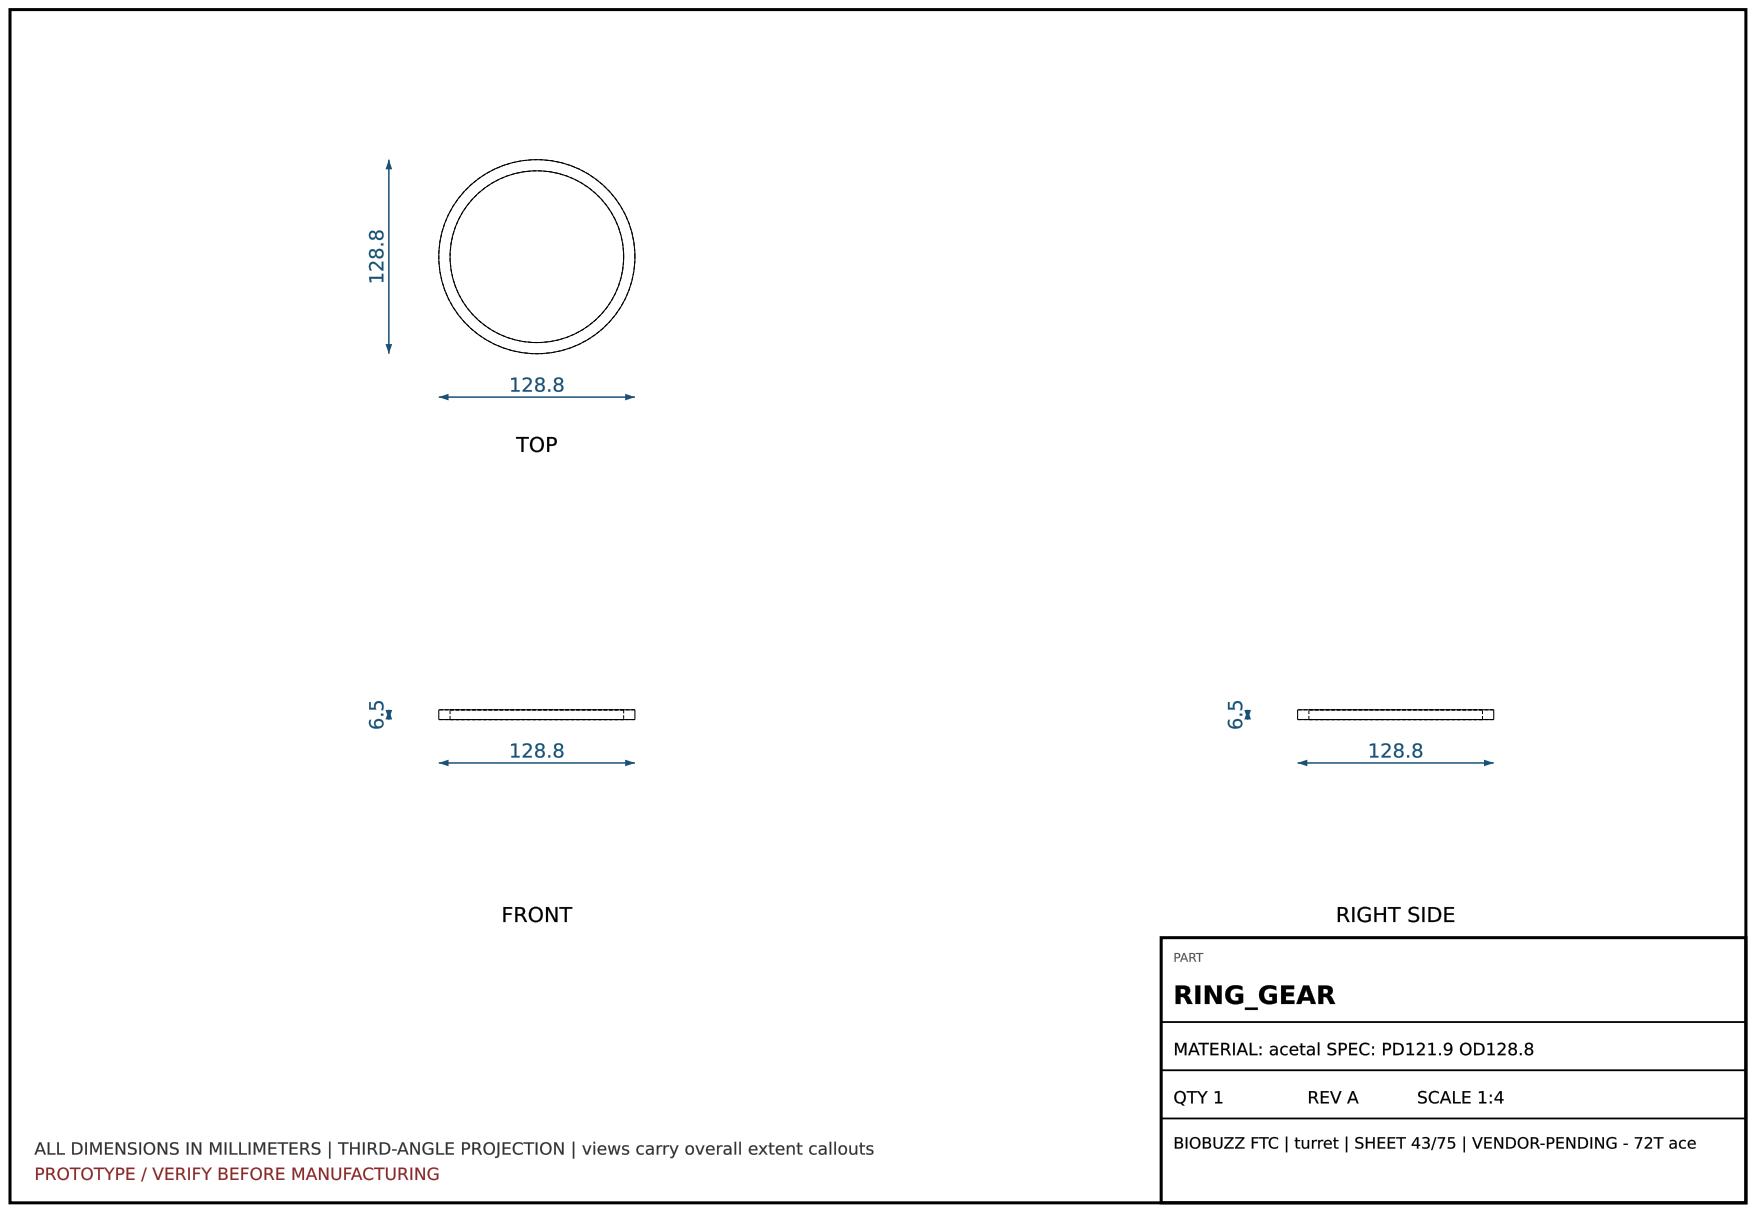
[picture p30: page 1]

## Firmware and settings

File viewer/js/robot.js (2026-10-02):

// robot.js — BIOBUZZ competition robot assembly (inches, Y-up, front = -Z)
//
// Positions follow the as-built CAD (cad/master_robot.FCStd, sprint-04 state),
// converted mm→in with: viewer.x = -cad.y/25.4, viewer.y = cad.z/25.4,
// viewer.z = -cad.x/25.4. Where the viewer can't express a real feature
// (ring-gear tooth profile, formed-plate flanges, chute lip flare, slot cutouts
// in round shells) a comment marks the deviation.
import * as THREE from 'three';
import { M } from './materials.js';
import * as P from './parts.js';

export const SUBS = {
  drive:       { label: 'Drivetrain & Frame',   color: '#9aa3ad', explode: new THREE.Vector3(0, -0.4, 0),  desc: '17.5×17.5 in. goBILDA-pattern U-channel chassis. 4× 96 mm mecanum wheels on live 8 mm REX hex axles, each coaxially driven by a 5203-class motor with a 5.2:1+ planetary gearbox through flange bearing blocks. Three dead-wheel odometry pods under the belly pan feed the pose estimator. Raised front crossmember doubles as the intake crown.' },
  intake:      { label: 'Intake',               color: '#2f7fd6', explode: new THREE.Vector3(0, -1.2, -5), desc: 'Full-width over/under dual-roller intake. Bottom: ribbed rubber traction roller ahead of the throat; top: stacked compliant star roller on torsion-spring floating mounts, offset behind and above the bottom roller — passes both 2.8" POLLEN and 3.6" NECTAR. #25 chain drive from a motor under the hopper incline; GT-belt cross-drive spins the star roller off the bottom shaft.' },
  hopper:      { label: 'Hopper & Feed',        color: '#37b34a', explode: new THREE.Vector3(0, 2.2, 0),   desc: 'Gravity-assisted ~21° inclined magazine (capacity ~6) in PETG/polycarb walls. Servo agitator paddle breaks jams at the low corner. Green compliant feed wheel meters single balls into the clear 4" feed column that rises through the turret axis — allowing unlimited turret yaw. A servo gate meters the column mouth; a Y-flap below the deck can divert a ball out the side port to the flower lift instead of the nip.' },
  turret:      { label: 'Turret',               color: '#e07ab8', explode: new THREE.Vector3(0, 4.6, 0),   desc: 'Split lazy-susan races (lower + upper) carry the launch deck: 4 mm PETG deck 244–248, susan 248–256.5, 72T ring gear 256.5–263, rotating plate 263–267. External ring mesh — the 14T pinion drives the ring outer rim at 72.8 mm center distance from a continuous-rotation servo at −Y of the turret axis. The feed column passes through the hollow center, so ammo supply is yaw-independent.' },
  launcher:    { label: 'Flywheel Launcher',    color: '#d9a406', explode: new THREE.Vector3(0, 7.6, 0),   desc: 'Dual counter-rotating 3.5" flywheels (independent 5203 motors → tunable spin differential) on a 73.7 mm nip gap. Servo-driven hood rides nearly flat on the rear pivot — sets exit angle ~40–65° for the HIVE cell lob. FLOWER deposits go to the lift (a 4" mouth for a 3.6" NECTAR is too tight a lob window). Vision camera rides the turret and tracks CELL AprilTags.' },
  lift:        { label: 'Flower Lift',          color: '#8e6fd8', explode: new THREE.Vector3(-2.6, 2.0, 3.2), desc: 'Two-stage cascade deposit lift on slim guide rails, dyneema-rigged from a continuous-servo winch with a traveling pulley on stage 1. The feed column doubles as the ball elevator: a servo Y-flap below the turret deck kicks one ball out the +Y side port, down the two-leg load chute (28.5°/21.8°, through a slot in the left tower cheek), and into the Ø99 mm tipping cradle. Raise +14.6" → cradle rim ~22.3" clears the ~21.5" FLOWER mouth (§9.7); a micro servo tips the ball in. Travel hard-stop collars satisfy R105/G416.' },
  electronics: { label: 'Electronics',          color: '#d97c1e', explode: new THREE.Vector3(0, -3.2, 0),  desc: 'REV Control Hub on the belly pan + Expansion Hub face-mounted on the right-rail outer wall. Twin polycarb side decks span the tower bays (standoffs to the rail tops) with a small shelf over the left deck, 3000 mAh battery with straps and main switch, color sensor at hopper entry, full motor/servo wiring loom.' },
};

export function buildRobot() {
  const robot = new THREE.Group();
  robot.name = 'robot';
  const groups = {}, anim = { intake: [], feed: [], fly: [], launch: {}, wheels: [] };
  const entries = [];

  for (const id in SUBS) {
    groups[id] = new THREE.Group();
    groups[id].name = id;
    robot.add(groups[id]);
  }

  // register a placed part instance; repeated (sub, name) pairs merge into one
  // BOM line so clicking any instance shows the true total quantity.
  // parent overrides the subsystem group (e.g. the rotating turret), with
  // pos/rot expressed in that parent's local frame.
  function reg(sub, name, spec, qty, notes, obj, pos = [0, 0, 0], rot = [0, 0, 0], parent = null) {
    obj.position.set(...pos);
    if (rot[0]) obj.rotation.x = rot[0];
    if (rot[1]) obj.rotation.y = rot[1];
    if (rot[2]) obj.rotation.z = rot[2];
    let e = entries.find(x => x.sub === sub && x.name === name);
    if (!e) { e = { name, sub, spec, qty: 0, notes, objs: [] }; entries.push(e); }
    e.qty += qty;
    e.objs.push(obj);
    obj.userData.entry = e;
    (parent || groups[sub]).add(obj);
    return obj;
  }

  // closed-belt loop between two pulleys — a smooth GT-profile band
  // (viewer deviation: belt drawn as a tube, no tooth detail)
  function beltLoop(c1, r1, c2, r2, x = 0, linkR = 0.045) {
    const g = new THREE.Group();
    const dy = c2[0] - c1[0], dz = c2[1] - c1[1];
    const d = Math.hypot(dy, dz), base = Math.atan2(dz, dy);
    const phi = Math.acos(THREE.MathUtils.clamp((r1 - r2) / d, -0.98, 0.98));
    const a1 = base + phi, a2 = base - phi;
    const pt = (c, r, a) => [c[0] + Math.cos(a) * r, c[1] + Math.sin(a) * r];
    const ring = [];
    ring.push(pt(c1, r1, a1), pt(c2, r2, a1));
    const n2 = Math.max(6, Math.round(2 * phi / 0.22));
    for (let i = 1; i <= n2; i++) ring.push(pt(c2, r2, a1 + (i / n2) * (a2 - a1)));
    ring.push(pt(c1, r1, a2));
    const n1 = Math.max(8, Math.round((2 * Math.PI - 2 * phi) / 0.22));
    for (let i = 0; i <= n1; i++) ring.push(pt(c1, r1, a2 + (i / n1) * (a1 - 2 * Math.PI - a2)));
    const curve = new THREE.CatmullRomCurve3(
      ring.map(p => new THREE.Vector3(x, p[0], p[1])), true, 'catmullrom', 0.02);
    const m = new THREE.Mesh(new THREE.TubeGeometry(curve, 80, linkR, 6), M.rubber);
    m.castShadow = m.receiveShadow = true;
    g.add(m);
    return g;
  }

  /* ================= DRIVETRAIN ================= */
  // as-built: rails ±160 mm (x ±6.30), wheels at cad y ±203.2 (x ±8.0) z ±127 (z ∓5.0)
  const RAIL_X = 6.3, RAIL_Y = 1.57, WHEEL_Y = 1.89, WHEEL_X = 8.0, WHEEL_Z = 5.0;
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

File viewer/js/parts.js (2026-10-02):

// parts.js — parametric FTC part library (dimensions in inches, Y-up world)
import * as THREE from 'three';
import { M, numberPlateTex, aprilTagTex, motorLabelTex, hubLabelTex } from './materials.js';

function shadowify(o) {
  o.traverse(m => { if (m.isMesh) { m.castShadow = true; m.receiveShadow = true; } });
  return o;
}
const G = (geo, mat) => shadowify(new THREE.Mesh(geo, mat));

// ---------- structural ----------

// goBILDA-style U-channel, extruded along Z, open face down-X by default.
// size = section width/height (1.89"), t = wall thickness
export function channel(len, mat = M.channel, withHoles = true) {
  const s = 1.89, t = 0.09;
  const g = new THREE.Group();
  // U profile extruded along Z: outer box minus inner cavity -> outline with hole
  const outer = new THREE.Shape();
  outer.moveTo(-s / 2, -s / 2); outer.lineTo(s / 2, -s / 2); outer.lineTo(s / 2, s / 2); outer.lineTo(-s / 2, s / 2); outer.closePath();
  const cavity = new THREE.Path();
  cavity.moveTo(-s / 2 + t, -s / 2 - 0.01); cavity.lineTo(s / 2 - t, -s / 2 - 0.01);
  cavity.lineTo(s / 2 - t, s / 2 - t); cavity.lineTo(-s / 2 + t, s / 2 - t); cavity.closePath();
  outer.holes.push(cavity);
  const geo = new THREE.ExtrudeGeometry(outer, { depth: len, bevelEnabled: false });
  geo.translate(0, 0, -len / 2);
  g.add(G(geo, mat));
  if (withHoles) {
    // 8mm grid holes — dark discs flush with each outer face
    const step = 0.315, r = 0.085;
    const n = Math.floor(len / step) - 1;
    const hole = new THREE.CylinderGeometry(r, r, 0.03, 12);
    hole.rotateZ(Math.PI / 2); // axis -> X
    const inst = new THREE.InstancedMesh(hole, M.holeDark, n * 2);
    const m4 = new THREE.Matrix4();
    let i = 0;
    for (let k = 0; k < n; k++) {
      const z = -len / 2 + (k + 1) * (len / (n + 1));
      for (const x of [s / 2 - 0.01, -s / 2 + 0.01]) {
        m4.makeTranslation(x, 0, z);
        inst.setMatrixAt(i++, m4);
      }
    }
    inst.count = i;
    g.add(inst);
    // top face hole strip (open face is -Y, no material there)
    const topHole = new THREE.CylinderGeometry(r, r, 0.03, 12);
    const inst2 = new THREE.InstancedMesh(topHole, M.holeDark, n);
    let j = 0;
    for (let k = 0; k < n; k++) {
      const z = -len / 2 + (k + 1) * (len / (n + 1));
      m4.makeTranslation(0, s / 2 - 0.01, z);
      inst2.setMatrixAt(j++, m4);
    }
    inst2.count = j;
    g.add(inst2);
  }
  return g;
}

export function plate(w, h, t = 0.09, mat = M.alu) {
  return G(new THREE.BoxGeometry(w, t, h), mat);
}
export function plateV(w, h, t = 0.09, mat = M.alu) { // vertical plate, w along X, h along Y
  return G(new THREE.BoxGeometry(w, h, t), mat);
}

export function gusset(w = 1.5, h = 1.5, t = 0.08, mat = M.accent) {
  const s = new THREE.Shape();
  s.moveTo(0, 0); s.lineTo(w, 0); s.lineTo(0, h); s.closePath();
  const geo = new THREE.ExtrudeGeometry(s, { depth: t, bevelEnabled: false });
  geo.translate(0, 0, -t / 2);
  return G(geo, mat);
}

export function standoff(len = 1, mat = M.alu) {
  return G(new THREE.CylinderGeometry(0.12, 0.12, len, 6).rotateX(Math.PI / 2), mat);
}

// ---------- fasteners & shafting ----------

export function bolt(len = 0.35) {
  const g = new THREE.Group();
  const shaft = G(new THREE.CylinderGeometry(0.055, 0.055, len, 10), M.bolt);
  const head = G(new THREE.CylinderGeometry(0.095, 0.095, 0.09, 10), M.bolt);
  head.position.y = len / 2 + 0.04;
  const socket = G(new THREE.CylinderGeometry(0.045, 0.045, 0.02, 6), M.holeDark);
  socket.position.y = len / 2 + 0.09;
  g.add(shaft, head, socket);
  return g;
}

export function hexShaft(len) { // 8mm REX — hex profile
  return G(new THREE.CylinderGeometry(0.157, 0.157, len, 6).rotateZ(Math.PI / 2), M.steel);
}

export function bearing() {
  const g = new THREE.Group();
  g.add(G(new THREE.CylinderGeometry(0.31, 0.31, 0.28, 20).rotateZ(Math.PI / 2), M.alu));
  const flange = G(new THREE.CylinderGeometry(0.55, 0.55, 0.06, 6).rotateZ(Math.PI / 2), M.alu);
  flange.position.x = 0.16;
  const bore = G(new THREE.CylinderGeometry(0.16, 0.16, 0.3, 12).rotateZ(Math.PI / 2), M.holeDark);
  // rubber seal ring around the bore
  const seal = G(new THREE.TorusGeometry(0.2, 0.035, 6, 18).rotateY(Math.PI / 2), M.rubber);
  seal.position.x = 0.13;
  g.add(flange, bore, seal);
  // 4 flange bolts
  const boltGeo = new THREE.CylinderGeometry(0.05, 0.05, 0.12, 6).rotateZ(Math.PI / 2);
  const inst = new THREE.InstancedMesh(boltGeo, M.bolt, 4);
  const m4 = new THREE.Matrix4();
  for (let i = 0; i < 4; i++) {
    const a = (i / 4) * Math.PI * 2 + Math.PI / 4;
    m4.makeTranslation(0.19, Math.cos(a) * 0.4, Math.sin(a) * 0.4);
    inst.setMatrixAt(i, m4);
  }
  g.add(inst);
  return g;
}

export function collar() {
  return G(new THREE.CylinderGeometry(0.22, 0.22, 0.18, 14).rotateZ(Math.PI / 2), M.darkSteel);
}

// ---------- gears ----------

// spur gear: teeth around a cylinder. Build along Y, caller rotates.
export function spurGear(teeth, pitchR, t = 0.24, mat = M.accent, hubR = 0.22) {
  const outer = pitchR + 0.09, root = pitchR - 0.07;
  const s = new THREE.Shape();
  const N = teeth;
  for (let i = 0; i < N; i++) {
    const a0 = (i / N) * Math.PI * 2, a1 = ((i + 0.35) / N) * Math.PI * 2;
    const a2 = ((i + 0.5) / N) * Math.PI * 2, a3 = ((i + 0.85) / N) * Math.PI * 2;
    if (i === 0) s.moveTo(Math.cos(a0) * root, Math.sin(a0) * root);
    s.lineTo(Math.cos(a1) * root, Math.sin(a1) * root);
    s.lineTo(Math.cos(a2) * outer, Math.sin(a2) * outer);
    s.lineTo(Math.cos(a3) * outer, Math.sin(a3) * outer);
    s.lineTo(Math.cos((i + 1) / N * Math.PI * 2) * root, Math.sin((i + 1) / N * Math.PI * 2) * root);
  }
  const hole = new THREE.Path(); hole.absarc(0, 0, hubR * 0.55, 0, Math.PI * 2, true); s.holes.push(hole);
  const geo = new THREE.ExtrudeGeometry(s, { depth: t, bevelEnabled: false });
  geo.translate(0, 0, -t / 2);
  geo.rotateX(-Math.PI / 2); // teeth in XZ plane, axis = Y
  const g = new THREE.Group();
  g.add(G(geo, mat));
  const hub = G(new THREE.CylinderGeometry(hubR, hubR, t + 0.12, 14), mat);
  g.add(hub);
  return g;
}

// ---------- wheels ----------
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

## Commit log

2026-09-26 baseline: pre-overhaul placeholder CAD state
    Snapshot of the tree as it existed when the CAD overhaul autobuild started (viewer-referenced placeholder model, selfcheck_rehaul02 gate). Sprint-01 rebuilds cad/ to the viewer architecture; this com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
    Generated with [Devin](https://devin.ai)
    [drivebase_concept_v01.FCStd, drivebase_concept_v01_20260920_212502.FCStd, drivebase_concept_v01_sprint02_20260920_112157.FCStd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]
2026-09-26 sprint-01: shared drivetrain builder - zero undeclared overlaps
    dt_build.py + partkit.py + robot_params.py build frame, drivetrain,
    odometry pods, and electronics geometry once; subsystem/master docs
    consume it identically. 492 solids / 2318 declared pairs / 0
    undeclared overlaps >0.5mm3. Journals (89), embeds (208), face
    contacts (109), mount joints (73) declared per contract A1-A5.
    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
2026-09-26 sprint-01: bore/pilot centered on bearing blocks; gates pass
    Genuine geometry fix: flange_bearing placed the REX bore and pilot boss at the plate min-corner instead of the block center (axle bore bored ~18mm off-axis). Probe: 0 undeclared overlaps across 550 solids.
    Generated with Devin (https://devin.ai)
2026-09-26 sprint-01: bore/pilot centered on bearing blocks; all gates pass
    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
    [AXLE_FL.step, AXLE_FR.step, AXLE_RL.step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]
2026-09-26 sprint-01 rework: geometry fixes, declaration honesty, full exports + 43-gate selfcheck
    Geometry:
    - seat 16 floating nuts (post_foot/tie_web double rail_wall subtraction)
    - bore motor socket on the motor axis -> AXLE<->MOTOR is a real journal
    - symmetric 1mm belly-pan slot for ODO_ARM_LAT_R
    - wheel width 33.29 -> 38.1 vendor spec (hub_w 30.1 fills plate span)
    - footprint: outboard washer dropped, nut8_h 5.5->5.0, rear number-plate
    bolts flipped head-in-cavity -> span 453.7x454.5 (>=2mm margin per
    planner amendment A1); frame box stays 444.5x444.5
    - bearing OUT bolts + rivnuts end inside the wall (were grazing plates)
    Declarations/exports:
    - emit_meta reclassifies pairs by measured geome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
    [AXLE_FL.step, AXLE_FR.step, AXLE_RL.step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]
2026-09-27 round-02 rework: bake world coords into STEP breps + per-part/master reimport bbox gates + bom family rows
    [AXLE_FL.step, AXLE_FR.step, AXLE_RL.step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]
2026-09-27 STEP root product named master_robot; gate skips assembly wrapper
    [AXLE_FL.step, AXLE_FR.step, AXLE_RL.step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]
2026-09-27 generator state: evaluator round-03 thread
2026-09-27 D13: viewer deviations corrected in sprint-02 (star roller, crossed belt)
2026-09-28 sprint-02: game-piece path geometry + fresh exports
    Dual over/under roller intake (ribbed lower + compliant star top on
    sprung float slides), crossed quarter-twist belt w/ tensioner, chain
    drive under hopper incline, pivoted cheek plates w/ slide travel,
    inclined magazine + metering feed wheel, ~4in column at turret axis,
    agitator servo, Y-flap diverter. Rebuilt all 5 FCStd; selfcheck
    geometry-clean; regenerated STEP (758 parts), renders, meta, BOM.
    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
    [AGIT_BRKT.step, AGIT_HORN.step, AGIT_PADDLE.step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]
2026-09-28 sprint-02 eval-01 remediation: real apertures, honest decls, verified gates
    Eval-01 findings (D1-D10) addressed:
    - COL_PORT/DIV_PORT aperture now 100mm bore + wall R76 notch; D93 sphere
    clears the whole +Y corridor (S11/S12 stations clean).
    - COL_WIN feed window enlarged to >=93 clear into the bore.
    - GEOB_ball_path now measures real station spheres with common().Volume
    across 13 stations (mouth..flange); GEOB_probe_pose checks swept poses
    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
    [AGIT_BRKT.step, AGIT_HORN.step, AGIT_PADDLE.step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]
2026-09-28 regenerate view-state + renders from final sprint-02 round-02 geometry
    [drivebase.FCStd, drivebase_view.FCStd, electronics.FCStd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]
2026-09-29 sprint-03 negotiation exchange 2: contract v2 folds evaluator critique (external ring mesh, resolved z-stack, two-leg chute, D93 lift stations, N1-N10 strengthenings)
2026-09-29 sprint-03 contract AGREED: pin C4 (S8=10,0,125) + C5 (S15/S16 ball-center); contract is the grading baseline
2026-09-29 sprint-03: turret + lift builders, subsystem docs, deck/rail bores
    dt_turret.py: towers + gussets on the deck, turret deck z244-248,
    split lazy-susan races 248-256.5, external 72T ring + 14T pinion yaw
    drive, rotating plate 263-267 with cheeks, dual flywheels at z308.5
    (raised from 292 -- wheel arcs collided with the column top/ring),
    hood + pivot bearings + servo, nip backplate, camera + LED, yaw
    magnet + hall sensor, service-loop wires in the r55-80 annulus.
    dt_lift.py: lift base notched around TIE_RB_L on the left rail web,
    guide posts + feet straddling base and splice plate, two-stage
    cascade mast (S1/S2 bars, trucks, ties, pulleys), stop collars,
    winch + baked dyneema run, cradle cup +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
    [lift.FCStd, turret.FCStd]
2026-09-29 sprint-03: chute mount rework, selfcheck03, exports/docs for turret+lift
    - dt_lift _chute: tray bed centered on the pinned path line (was offset
    half a width), lips flank the bed at +-48.5, port ear welded beside
    the bore mouth instead of blocking it, tower pad straps the riser
    west of the slot with 2 through-bolts + nuts, leg-2 west lip notched
    at the riser sheet, lip screws reach the bed.
    - dt_lift/dt_turret: bake rotated/raw placements into vertices before
    _feat (Placement.Base bind zeroes translations on non-boolean
    shapes) -- lips + VOL_HOOD_HI landed at origin otherwise.
    - robot_params: fly_axis_z 292->308.5 (wheels cleared the column top,
    susan races, ring gear), hood_pi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
    [robot_params.py, selfcheck_overhaul03.py]
2026-09-30 Sprint-03 checkpoint: rebuilt subsystem docs, exports, renders after chute/cradle/tower rework
    Work-in-progress checkpoint before HUB_EXP relocation. All FCStd docs,
    STEP exports, view copies, renders and metadata regenerated following the
    chute path correction (leg2 31deg), cradle redesign (thin riser + west
    journal ear), tower window/slot changes, winch/pulley relocation, and
    turret flywheel/hood height corrections. S17 ball still conflicts with
    the shelf-mounted expansion hub; relocation in progress.
    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
    [AGIT_BRKT.step, AGIT_HORN.step, AGIT_PADDLE.step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]
2026-09-30 Add cad-verify workflow: FreeCAD build + selfcheck gates on push to main
2026-09-30 engineering-drawing pipeline: TechDraw sheets (PDF+SVG) + plate DXF profiles
    scripts/freecad/drawing_kit.py - part enumeration (same rules as
    export_step.py), identical-part grouping, plate detection, TechDraw
    page/view/extent-dim creation, A4-landscape sheet composition, headless
    PDF via QSvgRenderer+QPdfWriter, DXF R12 flat profiles via
    TechDraw.projectToDXF
    scripts/freecad/make_drawings.py - driver: every subsystem doc +
    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
    [drivebase_BELLY_PAN.dxf, drivebase_CLAMP_FL_2.dxf, drivebase_DECK_L.dxf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]
2026-09-30 keep bulk drawing output out of git: gitignore exports/drawings/*, commit manifest + sample/
    574 PDF+SVG sheet pairs (~140 MB) made the diff unreviewable — Devin
    Review errored twice on it. The full set is regenerated per run; the
    repo now carries manifest.json/txt plus a curated sample/ (10 sheets +
    4 DXFs across drivebase, turret, intake, hopper, lift, electronics,
    master).
    [drivebase_BELLY_PAN.dxf, drivebase_CLAMP_FL_2.dxf, drivebase_DECK_L.dxf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]
2026-09-30 drawing pipeline: review fixes — better dedup signature, DXF plate alignment, scale text, fresh outputs, SHEET/SCALE fields, exit code
    - group_identical signature now includes face/edge counts (bbox+volume
    alone merged distinct near-cuboid parts)
    - flat_profile_dxf premultiplies the face->Z rotation onto the part's
    own placement instead of replacing it (correct for rotated plates)
    - scale_text prints true ratios via %g (0.4 -> 1:2.5, not 1:2)
    - is_plate excludes belts/cables/chains/springs/tubes by name
    - title block now fills SCALE (projected-bbox estimate) and SHEET n/m
    where m counts only the parts this run emits
    - run start deletes stale pdf/svg/dxf outputs so vanished parts do n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
2026-09-30 sprint-03: resolve remaining integration/verification failures
    Geometry fixes:
    - YAW_TRAY widened (56x39) with bolts relocated to south strip,
    clearing YAW_SERVO can and YAW_SHAFT
    - TWC_L cap bolts moved onto surviving east cap block (x-18/-8) where
    both deck (head seat) and cap (nut seat) survive the port+window
    - GUD_R3 deck-foot bolts removed (fly-motor notch leaves no stock)
    - BOLT_SC_R flipped to head-north; SC bolt z dropped to clear
    LIFT_TOP_TIE / ROPE_GUIDE / BOLT_LTT
    - LIFT_S2_TIE widened west+east; BOLT_S2TIE -> screws relocated clear
    of LIFT_PULLEY / S1 bars / CRADLE_ARM tab
    - SCRW_CARM moved west off LIFT_S2_BAR shank zone
    - SCRW_S1T shifted 1.5mm west off S2 truck corner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
    [AGIT_BRKT.step, AGIT_HORN.step, AGIT_PADDLE.step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]
2026-09-30 sprint-03: parametric propagation fixes (tower/plate/stop-z formulas) + stale roller decls
    [drivebase.FCStd, electronics.FCStd, hopper.FCStd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]
2026-10-02 docs: independent eval of main @ HEAD — sprint-03/04 state (#4)
    Cold-read adversarial eval on FreeCAD 1.1.3: all three gates verified
    (45/45, 61/61, 73/73), rebuilds geometry-identical (FCStd bytes differ
    on serialization noise only), 1106/1106 STEPs reimport, yaw/susan/
    envelope/mounts/exports all measured PASS. Ball path graded FAIL:
    launch wiring crosses the S13->S14 corridor (<=151mm3) and port
    fasteners graze the sphere on the only feasible transition.
2026-10-02 sprint-04: viewer as-built resync + drawings refresh + docs (#3)
    * viewer: resync robot model to as-built CAD geometry
    Rewrites viewer/js/robot.js against the real FCStd world geometry
    (census of ~570 placed parts from master_robot.FCStd via world
    bounding boxes) so the design-review app matches the built robot:
    - external yaw ring mesh: 72T ring on the turret outer rim, 14T
    pinion at 72.8mm c.d., yaw servo at -Y of the turret axis
    - split lazy-susan races + resolved z-stack (deck 244-248 /
    susan 248-256.5 / ring 256.5-263 / plate 263-267)
    - two-leg LOAD_CHUTE (28.5deg + 21.8deg) from column port to cradle
    - cradle bore Ø99 at park z~140; Ø2.17 pivot + foam-lined cup
    - electronics ex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
    [parts.js, robot.js]
2026-10-03 docs: independent eval r2 — verify-first pass on main @ b1ceb92
    Second independent evaluation (own freecadcmd probes): all gate
    scores verified (45/45, 61/61, 73/73), geometry-deterministic
    rebuilds (15136/15136 sigs identical; FCStd bytes differ), 1106
    STEP files reimport clean, susan/yaw/envelope/mounts/exports PASS.
    Ball path FAIL upheld: WIRE_FLY_L 621mm3 + WIRE_CAM_USB 0.21mm graze
    in launch corridor, ROPE_DYNEEMA 80mm3 on cradle approach,
    BOLT_PORT graze 1.13mm. Report only, no production edits.
2026-10-03 design finish: ball-path relief + repo cleanup + CAD-team README (#5)
    * design: relieve ball-path grazes (wire reroute, lip-screw stations, port-ear bolts)
    - WIRE_FLY_L y=0-crossing moved x -114->-120 (outside launch-corridor sphere reach)
    - WIRE_CAM_USB approach waypoints pushed outboard of S13->S14 corridor
    - LIP_TS leg-1 screw stations moved past the S12->S15 transition zone
    - CHUTE_PORT_EAR + BOLT_CHP_* shifted 3.5mm outboard to clear the transition
    - all FCStd rebuilt under FreeCAD 1.1.3
    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
    [AGIT_BRKT.step, AGIT_HORN.step, AGIT_PADDLE.step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]
